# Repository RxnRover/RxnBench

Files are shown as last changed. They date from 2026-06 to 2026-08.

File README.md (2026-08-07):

# Rxn Bench - DIY Automated Chemistry Bench

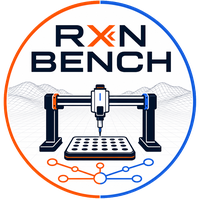
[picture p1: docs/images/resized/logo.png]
Rxn Bench logo


## Table of Contents

- [Overview](#overview)
- [Navigating this repository](#navigating-this-repository)
- [Requirements](#requirements)
- [Usage](#usage)
- [Implementation and design](#implementation-and-design)
- [Gallery](#gallery)
- [References and helpful material](#references-and-helpful-material)
- [Authors and Contributors](#authors-and-contributors)

## Overview

Rxn Bench is a DIY automated chemistry bench built on a repurposed Sovol SV08 3D printer as the XYZ motion platform, with an Atlas Scientific probe for pH sensing. A Raspberry Pi on the printer runs Klipper/Moonraker plus SiLA2 device servers for the gantry and pH sensor; a separate operator machine runs a frontend application [Rxn Bench](TODO: Eventually include repo link) that talks to those servers over gRPC/SiLA, and experiment scripts drive the bench through a Python client [Rxn Bench Client](TODO: Eventually include repo link).

### Motivation

Machine learning, high-throughput screening, and AI-assisted discovery all depend on large, reliable experimental datasets, and generating that data by hand is slow, inconsistent, and labor-intensive. Commercial automation platforms solve the repeatability problem, but most are costly, specialized, and locked to specific hardware and workflows - out of reach for many labs. Rxn Bench is a low-cost, modular alternative: off-the-shelf hardware, open lab-software frameworks, and customizable 3D-printed components, letting a lab integrate diverse devices, adapt workflows, and generate data at scale for under $1000.

## Navigating this repository

- [`rxnbench/`](rxnbench/) - app code that isn't specific to one device: `frontend/` (the desktop UI shell, discovery, device selection, generic fallback UI) and `backend/` (the uv workspace root, the shared `client/` Python API, install scripts).
- [`devices/`](devices/) - one self-contained plugin per physical device (`gantry`, `ph_sensor`, `camera`, `dosing_pump`), each split into a `capability/` (the SiLA2 server + operator-UI widget - hardware-agnostic) and a `driver/` (the actual vendor hardware code that plugs into it, plus that hardware's CAD and any mount/toolhead config). See [Supported-Devices.md](Supported-Devices.md) for which driver backs which capability. A device folder can be dropped in or removed without touching the app shell.
- [`hardware_models/`](hardware_models/) - placeholders for future devices without hardware yet. Each existing device's CAD lives with its driver instead - see `devices/<name>/driver/hardware_models/`.
- [`docs/`](docs/) - usage/deployment guides, architecture and design docs, datasheets, and the images used throughout this README.
- [`notes/`](notes/) - working notes.

See [docs/ai/CURRENT_STATE.md](docs/ai/CURRENT_STATE.md) for the full architecture snapshot, package layout, and active design decisions.

## Requirements

- A Sovol SV08 3D printer (or similar Klipper-based motion platform) and a computer device (__e.g. a Raspberry Pi 5__) to control it
- Python 3.10+ and [`uv`](https://docs.astral.sh/uv/) on both the Pi (backend) and the operator machine (frontend)
- Atlas Scientific EZO pH kit and 3D-printed mounts (see Component List below) for pH sensing hardware

## Usage

See [docs/usage.md](docs/usage.md) for commands to install dependencies and start the backend servers (real or mocked) and the frontend UI.

## Implementation and design

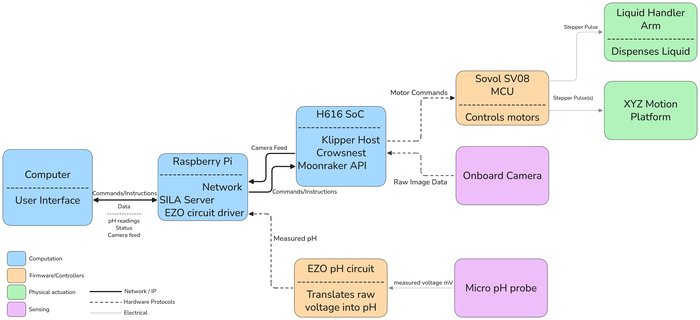
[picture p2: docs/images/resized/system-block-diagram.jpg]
Rxn Bench high-level system block diagram: operator UI talks to the Raspberry Pi's SILA server, which drives the Sovol SV08 MCU (XYZ motion), and the EZO pH circuit/probe


Rxn Bench is a modular lab-automation platform for programmable scientific workflows, built from a repurposed SOVOL SV08 3D printer with
custom 3D-printed components and open software interfaces.

### Capability-based hardware abstraction

Devices are represented through
SiLA2 feature servers running on a backend computer (e.g., a Raspberry Pi),
which expose standardized commands and properties for each capability:
pH sensor, gantry, pump, etc. New hardware plugs into the same feature
interface, so a device can be swapped or added with minimal frontend
and backend changes. If it walks like a duck and talks like a duck, it's
treated as a duck.

### Desktop control + Python API

[Rxn Bench](TODO: Eventually include repo link) provides a desktop
interface for configuration and direct device control, while a [Rxn Bench Client](TODO: Eventually include repo link) API
enables headless operation and experiment scripting.

### Component List

#### Motion Platform

| Name | Link | Purpose |
| --- | --- | --- |
| SV08 3D Printer | [MatterHackers](https://www.matterhackers.com/store/l/sovol-sv08-enclosed-pre-assembled-3d-printer/sk/MQ7MC2AK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) | XYZ motion platform base for liquid handler automation |
| Raspberry Pi 5  | [PiShop](https://www.pishop.us/product/raspberry-pi-5-8gb/?src=raspberrypi) | Main controller for coordinating motion and sensors |

#### pH Sensor

| Name | Link | Purpose |
| --- | --- | --- |
| Atlas Scientific EZO Micro pH Kit | [Atlas Scientific](https://atlas-scientific.com/kits/micro-ph-kit/) | Complete kit for pH measurement |
| Atlas Scientific EZO pH Circuit | [Atlas Scientific](https://atlas-scientific.com/embedded-solutions/ezo-ph-circuit/) | Embedded pH signal processing circuit |
| pH Isolation Board | [Atlas Scientific](https://atlas-scientific.com/carrier-boards/electrically-isolated-ezo-carrier-board-gen-2/) | Electrically isolates pH circuit to prevent noise/interference |
| Half-Cell pH Isolation Board | [Atlas Scientific](https://atlas-scientific.com/carrier-boards/half-cell/) | Carrier board for half-cell pH probe configurations |
| Spear Tip pH Probe | [Atlas Scientific](https://atlas-scientific.com/probes/spear-tip-ph-probe/) | Soil/spear-tip combination electrode; male SMA connector, mates directly to isolation carrier board |

#### Labware

##### Workspace

A workspace is a YAML-defined deck layout ([`devices/gantry/capability/backend/src/rxn_bench_gantry/workspace/`](devices/gantry/capability/backend/src/rxn_bench_gantry/workspace/)) that tells the gantry backend which labware sits where: sample plates, wash/waste beakers, a calibration station, and the washing station can all be mixed in whatever arrangement fits the deck and the experiment. Swapping workspaces (or editing one in the desktop UI's workspace editor) is a config change, not a rebuild - see [docs/usage.md](docs/usage.md) for how to load one.

##### Sample-Plates

3D-printed plate/tube holders that snap onto the deck's footprint grid. Each is a YAML labware definition under [`devices/gantry/capability/backend/src/rxn_bench_gantry/labware/`](devices/gantry/capability/backend/src/rxn_bench_gantry/labware/), the single source of truth for well geometry, plate height, and the gantry's clearance/engagement-depth math.

| Name | Wells | Purpose |
| --- | ----- | --- |
| 96-Well Standard Plate | 8x12  | High-density standard well plate  |
| 24-Well Standard Plate | 4x6 | Square-well standard plate |
| 24-Well Sample Holder (5 mL) | 4x6 | Holds 5 mL vials |
| 24-Well Sample Holder (15 mL)  | 4x6 | Holds 15 mL vials |
| 15-Well Sample Holder | 3x5 | Holds large-format samples |
| 6-Well Sample Holder (25 mL) | 2x3 | Holds 25 mL vials |
| 6-Well Sample Holder (50 mL) | 2x3 | Holds 50 mL vials |
| 3-Well Sample Holder | 1x3 | Holds large-diameter samples |
| 100 mL Beaker Holder | 1x1 | Wash/waste reservoir |

##### Footprints

Every piece of labware shares the same footprint (127.76 x 85.48 mm - the ANSI/SBS standard microplate footprint), so any plate, tube holder, beaker, or the washing station locks into the same modular grid of mounting tiles on the deck. Swapping a 6-well tube rack for a 96-well plate is a matter of physically swapping footprints and pointing the workspace YAML at the new labware, not redesigning the deck.

##### Washing-Station

A 3D-printed cup, routed to waste through tubing, used to rinse the pH probe (or future pipette tips) between wells. It is defined as its own labware footprint ([`washing_station.yaml`](devices/gantry/capability/backend/src/rxn_bench_gantry/labware/washing_station.yaml)) so it slots into a workspace exactly like any other plate.

###### Liquid Handler (In-progress)

| Name | Link | Purpose |
| --- | --- | --- |
| Pipette Cone Assembly | [PipetteSupplies](https://www.pipettesupplies.com/product/e1-clip-tip-tip-cone-assembly-single-channel-1250-l-t/) | Actual liquid displacement mechanism |
| Stepper Linear Actuator | [Haydon Kerk Pittman](https://www.haydonkerkpittman.com/products/linear-actuators/can-stack-stepper) | Pushes the pipette plunger to aspirate/dispense liquid |

#### Extra Peripherals

| Name | Link | Purpose |
| --- | --- | --- |
| SMA Male-to-Female Extender Cable | [Atlas Scientific](https://atlas-scientific.com/accessories/sma-extender/) | Extends the probe cable reach from the carrier board to the mounted probe |

#### Other components/items

| Name | Link | Purpose |
| --- | --- | --- |
| Bambu Lab A1 | [BambuLabs](https://bambulab.com/en-us/a1) | Unmodified used to 3D print platforms, plates, etc. |

## Gallery

### Assembled bench

| Assembled, pipette over a well plate | Running on the bench next to the operator laptop |
| --- | --- |
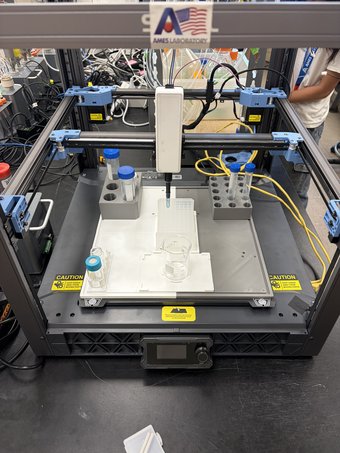
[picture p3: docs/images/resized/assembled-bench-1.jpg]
Assembled Rxn Bench with the pipette toolhead positioned over a well plate
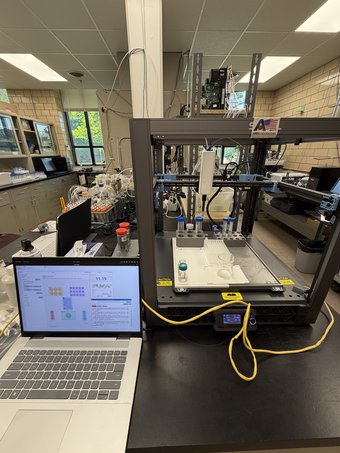
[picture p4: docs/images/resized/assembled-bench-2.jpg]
Rxn Bench running on the lab bench next to the operator laptop running the frontend UI
|  |  |

### pH probe toolhead

CAD design next to the assembled 3D-printed housing around the Atlas Scientific EZO pH circuit and probe.

| CAD design | Assembled |
| --- | --- |
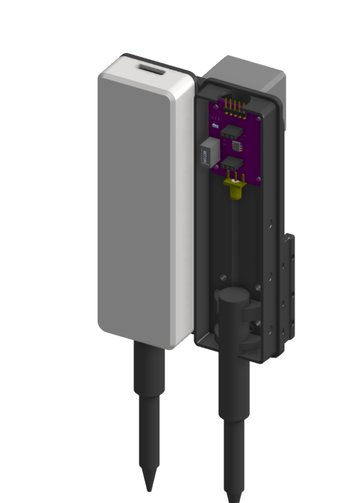
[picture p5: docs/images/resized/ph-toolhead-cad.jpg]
CAD render of the pH probe toolhead, exploded to show the EZO pH circuit board inside
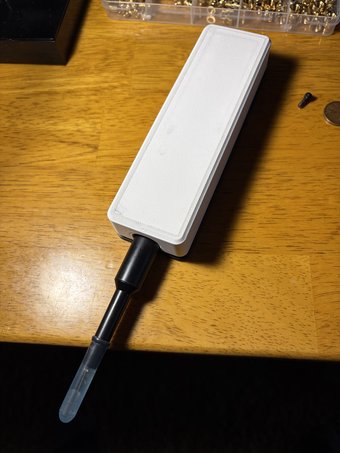
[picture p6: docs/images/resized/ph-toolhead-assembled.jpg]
Assembled 3D-printed pH probe toolhead housing
|  |  |

### Toolhead docking mount

The gantry docks multiple toolheads via a 3D-printed mount with linear-rails, in the spirit of the tool-changer designs linked below.

| CAD design | Assembled |
| --- | --- |
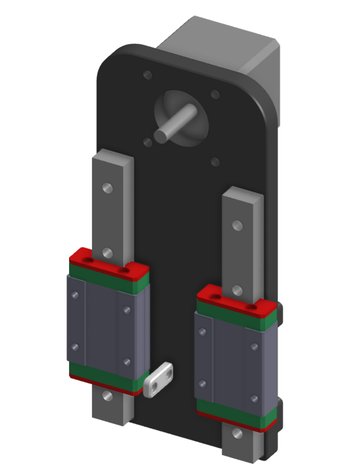
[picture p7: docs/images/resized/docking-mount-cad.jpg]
CAD render of the toolhead docking mount with linear rail bearings
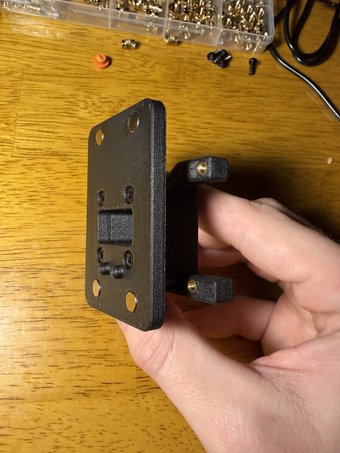
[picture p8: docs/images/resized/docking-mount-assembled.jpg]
Assembled 3D-printed toolhead docking mount
|  |  |

### Labware

#### Workspace

| Planned layout | Assembled deck |
| --- | --- |
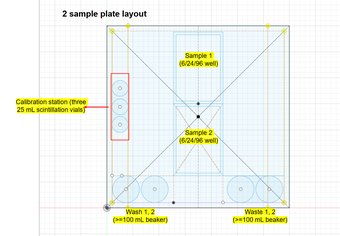
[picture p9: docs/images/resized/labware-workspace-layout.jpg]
Example workspace layout diagram showing sample plates, wash/waste beakers, a calibration station, and a pipette-tip disposal zone arranged on the deck
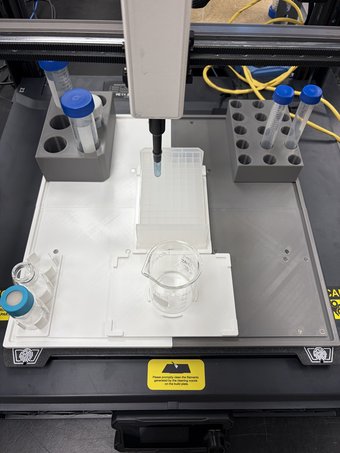
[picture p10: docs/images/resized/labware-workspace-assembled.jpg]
Assembled deck with sample holders, a 96-well plate, and a beaker mounted on the footprint grid
|  |  |

#### Sample-Plates

| 24-Well Sample Holder | 15-Well Sample Holder |
| --- | --- |
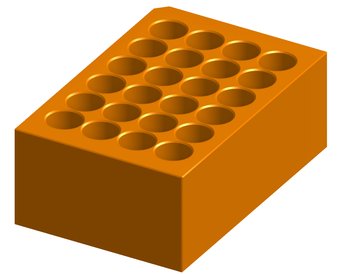
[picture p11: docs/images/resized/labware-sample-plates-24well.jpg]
CAD render of the 24-well sample holder block
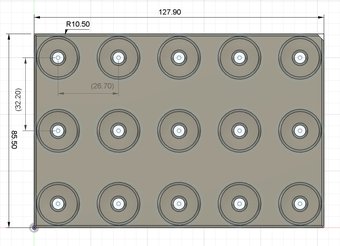
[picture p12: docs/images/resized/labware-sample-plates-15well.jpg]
Dimensioned CAD drawing of the 15-well sample holder
|  |  |

#### Footprints

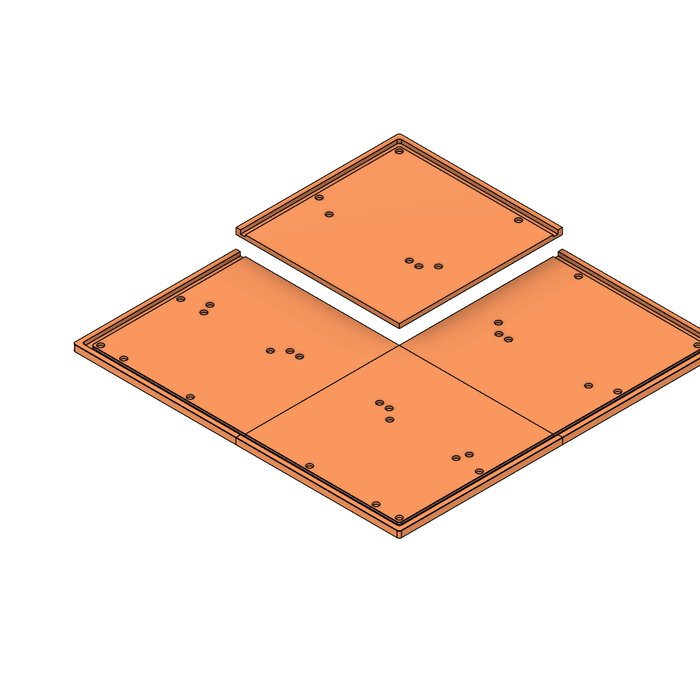
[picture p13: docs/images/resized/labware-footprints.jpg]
CAD render of the modular footprint tiles that labware mounts onto, shown apart from the deck


#### Washing-Station

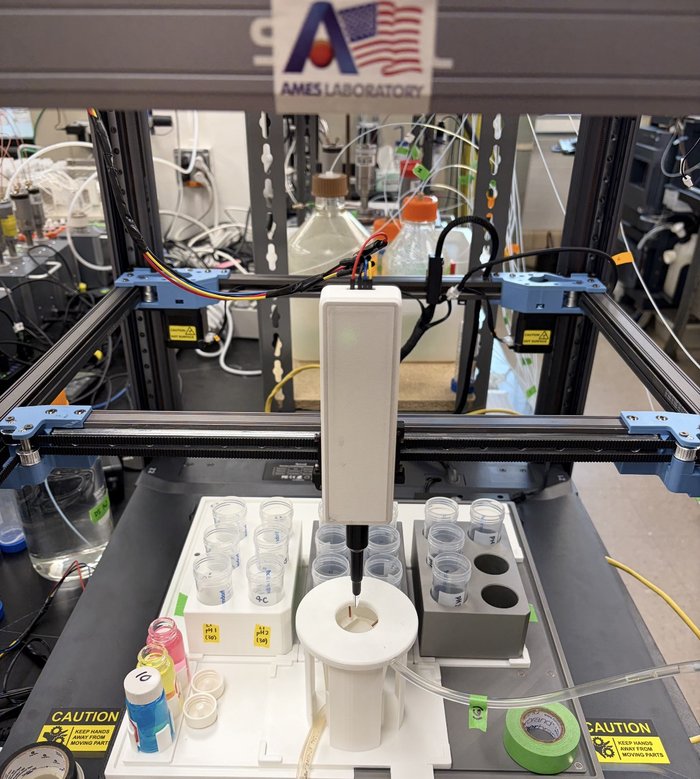
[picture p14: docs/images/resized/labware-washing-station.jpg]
The pH probe toolhead docked over the washing station cup, flanked by sample holders on the deck


### Rxn Bench UI

#### Main interface

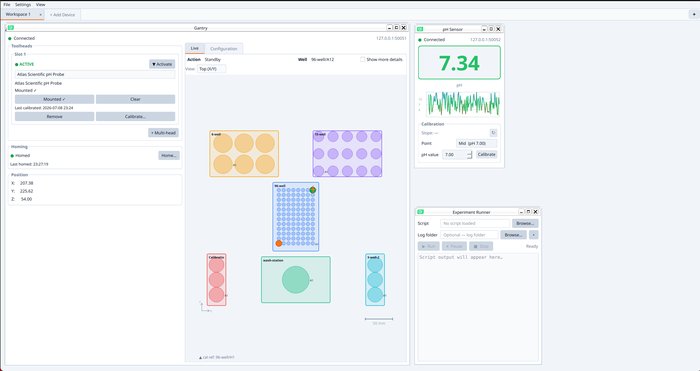
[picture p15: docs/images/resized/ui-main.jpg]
Rxn Bench UI main screen showing the Gantry widget, pH Sensor widget, and Experiment Runner widget


#### Sensor and control widgets

| Gantry | pH Probe | Experiment Runner |
| --- | --- | --- |
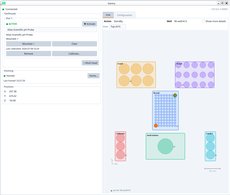
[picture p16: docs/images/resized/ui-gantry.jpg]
Gantry view
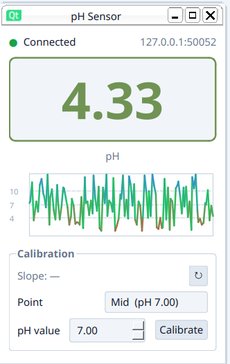
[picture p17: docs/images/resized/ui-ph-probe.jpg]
pH Probe view
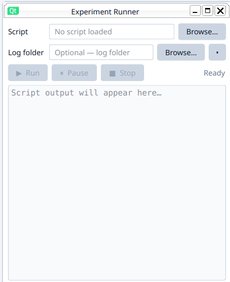
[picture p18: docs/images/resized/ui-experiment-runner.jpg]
Experiment Runner view
|  |  |  |

#### Adding a device

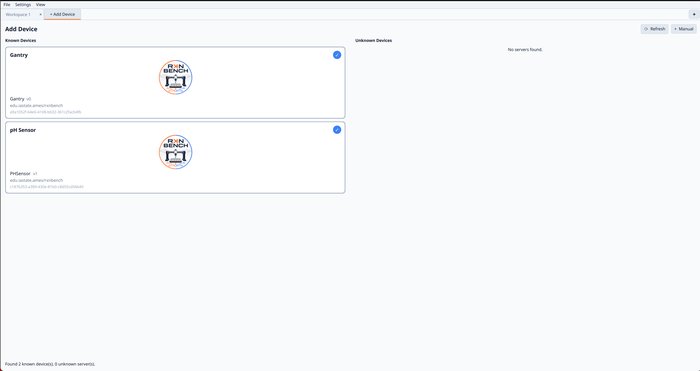
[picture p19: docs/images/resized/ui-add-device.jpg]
Add Device view


## References and helpful material

### Core

- [How to convert a 3D printer to a personal automated liquid handler for life science workflows](https://www.sciencedirect.com/science/article/pii/S2472630324001213#bib0043)
- [Opentrons](https://opentrons.com/) - commercial lab-automation platform, referenced for cost/rigidity comparison
- [SILA Standard](https://sila-standard.com/standards/)
- [SILA Standard GitLab](https://gitlab.com/SiLA2)
- [Klipper Firmware](https://www.klipper3d.org/)
- [SOVOL SV08 GitHub](https://github.com/Sovol3d/SV08)
- [Raspberry Pi Docs](https://www.raspberrypi.com/documentation/computers/raspberry-pi.html)
- [Crowsnest](https://docs.mainsail.xyz/crowsnest/)
- [Moonraker](https://moonraker.readthedocs.io/en/latest/)
- [Pipette Clip Tip](https://www.thermofisher.com/us/en/home/life-science/lab-plasticware-supplies/pipettes-pipette-tips/pipette-tips/products/cliptip-pipette-system.html)

### Related open-source lab automation projects

- [Rxn Rover](https://rxnrover.github.io/) - Ames National Lab Automation Platform
- [Science Jubilee](https://science-jubilee.readthedocs.io/) - open-source tool-changing lab robot with pipette, camera, and sensor tools
- [Jubilee: An Extensible Machine for Multi-tool Fabrication (paper)](https://www.researchgate.net/publication/341697828_Jubilee_An_Extensible_Machine_for_Multi-tool_Fabrication)
- [Automated Liquid Handler from a 3D Printer - Journal of Chemical Education](https://pubs.acs.org/doi/10.1021/acs.jchemed.3c00855)
- [E3D Tool Changer R&D](https://e3d-online.com/blogs/news/research-and-development-motion-system-and-tool-changer) - commercial tool-changer that inspired Jubilee's docking mechanism
- [GitHub - totaldesaster/toolchanger](https://github.com/totaldesaster/toolchanger) - low-cost 3D-printed tool changer mechanism
- [EvoBot: Open-Source Modular Liquid Handling Robot](https://www.mdpi.com/2076-3417/10/3/814)
- [Open-source personal pipetting robots (Nature Communications)](https://www.nature.com/articles/s41467-022-30643-7)

## Authors and Contributors

### Co-authors

__John Brittain__* - Software development, system design, hardware design, fabrication, integration, and project lead for the Rxn Bench platform.

__Felisha Kuo__* - Experimental setup, laboratory workflow development, hardware fabrication, testing, and project lead for the chemistry-side integration.

__David Lee__ - Laboratory expertise, practical setup support, equipment ordering, and experimental workflow insight.

__Lun An__ - Chemistry supervision, project planning, experimental guidance, chemistry expertise, and technical review.

__Long Qi__ - Project sponsorship, overall direction, supervision, planning, and organizational guidance.

__Zachery Crandall__ - Engineering and software supervision, project planning, technical guidance, and formal review.

*These authors contributed equally to the work.

### Acknowledgements

This work was supported by the [SuLI internship program](https://science.osti.gov/wdts/suli) at [Ames National Laboratory](https://www.ameslab.gov/). The authors thank the program organizers and mentors for providing the opportunity, resources, and guidance that made this project possible.

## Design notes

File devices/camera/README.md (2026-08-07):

# Camera

Streams periodic still images over SiLA. `CameraProtocol` only requires a `capture() -> bytes` method, so the capability doesn't care what's behind it.

- **`capability/`** - the SiLA feature + PySide6 widget. `capability/backend/` is `rxn-bench-camera` (port 50053, runs on the device host alongside `rxn-bench-gantry`/`rxn-bench-ph` - a Raspberry Pi in the reference deployment). `capability/frontend/` is the Camera device plugin (live image view, capture-interval control). See [capability/backend/README.md](capability/backend/README.md) for the full SiLA feature list.
- **`driver/`** - `rxn-bench-crowsnest-camera-driver`, which pulls stills from a Crowsnest-managed webcam over HTTP (initial target: the Crowsnest stream on the SOVOL SV08's own controller). Swap this for a different camera source's driver without touching the SiLA feature or widget. See [Supported-Devices.md](../../Supported-Devices.md).

`capability/backend/` and `driver/backend/` both only ever run on the device host; `capability/frontend/` only ever runs on the operator machine as part of `rxn_bench_ui` (SiLA/gRPC only, no direct imports). See [docs/ai/CURRENT_STATE.md](../../docs/ai/CURRENT_STATE.md) for the full architecture.

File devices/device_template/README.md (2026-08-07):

# device_template

Boilerplate for adding a new device to the rxn bench, not a real device itself. Copy this whole folder to `devices/<name>/` and follow the checklist.

- **`capability/`** - reference SiLA feature + widget. `capability/backend/` is the reference SiLA2 server package (`rxn_bench_template`), with `TODO`-marked stubs for the hardware `Protocol`, SiLA feature, mock, and server wiring. Start here: [capability/backend/README.md](capability/backend/README.md) has the full step-by-step checklist for renaming and wiring things up. `capability/frontend/` is the reference device plugin: a minimal hand-built widget (no `.ui` file) plus the standard connection layer. Wire decoding uses compiled protobuf stubs in `capability/frontend/src/rxn_bench_device_template_frontend/proto/`, generated from the device's manifest entry in `rxnbench/backend/scripts/gen_proto.py` (run `make gen-proto` from `rxnbench/backend`). Delete the frontend half if your device doesn't need a custom widget yet - unrecognized servers fall back to the generic `GenericDeviceWidget`.

There's no `driver/` here on purpose - this template's mock is a generic Protocol stub, not real vendor hardware, so there's nothing to split out yet. A real device usually does need one: see `devices/ph_sensor/` for the fullest worked example (a driver with two transports, hardware CAD, and a toolhead config) and [Supported-Devices.md](../../Supported-Devices.md) for how capability/driver packages register with each other.

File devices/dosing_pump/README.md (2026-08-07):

# dosing_pump

Dosing pump SiLA feature, exposed as `DosingPump` on port **50054**. Hardware-agnostic - the reference hardware is the Atlas Scientific **EZO-PMP**, but that's a driver, not baked into the feature.

- **`capability/`** - the SiLA feature + PySide6 widget. `capability/backend/` is `rxn-bench-dosing-pump`. `capability/frontend/` is the widget: dispense / dose-over-time / flow-rate controls, live dispensed volume, totals. See [capability/backend/README.md](capability/backend/README.md) for the command set.
- **`driver/`** - `rxn-bench-atlas-ezo-pmp-driver`, the Atlas Scientific EZO-PMP UART driver (including its mock - see "Reusing this for a different pump" below for why the mock lives here too). Swap this for a different pump's driver without touching the SiLA feature or widget. See [Supported-Devices.md](../../Supported-Devices.md).

## Hardware at a glance

| | |
|---|---|
| Flow rate | 0.5 - 105 ml/min open-loop (with the supplied tubing) |
| Metered rate ceiling | Lower than 105, reported by `DC,?`, set by calibration |
| Smallest dispense | 0.5 ml |
| Accuracy | ±1% (after calibration) |
| Data protocol | UART (implemented) or I2C, ASCII |
| UART default | 9600 baud, 8N1, CR-terminated |
| Power | 3.3-5.5 V logic **and** 12-24 V motor (two supplies) |

Datasheet: [docs/datasheets-manuals/EZO-PMP/EZO_PMP_Datasheet.pdf](../../docs/datasheets-manuals/EZO-PMP/EZO_PMP_Datasheet.pdf)

## Operating modes

All four datasheet modes are exposed:

| Mode | SiLA command | EZO command |
|---|---|---|
| Volume dispensing | `Dispense(Volume)` | `D,[ml]` |
| Dose over time | `DoseOverTime(Volume, Minutes)` | `D,[ml],[min]` |
| Constant flow rate | `SetFlowRate(Rate, Minutes)` | `DC,[ml/min],[min\|*]` |
| Continuous dispensing | `DispenseContinuously(Reverse)` | `D,*` / `D,-*` |

Dispense-at-startup (`Dstart`) is deliberately not exposed - it configures the pump to run on power-up without a client, which works against having the bench drive it.

### Two different maxima

These are easy to conflate:

- **~105 ml/min** - the pump's *open-loop* top speed with the supplied tubing, and the datasheet cover's "0.5ml to 105ml/min". This is what **Continuous** (`D,*`) runs at. It takes no rate argument; the motor just runs flat out.
- **`MaxFlowRate` (`DC,?`)** - the fastest rate the pump can *regulate* to in **Constant rate** mode. Substantially lower (the datasheet's example is 58.5 ml/min) and "determined after calibration". Asking `SetFlowRate` for more returns `*TOOFAST`.

So a rate you can *hold* is always below the rate the pump can *reach*. To run continuously **at a chosen rate**, use Constant rate with an open-ended duration (`DC,[rate],*`) - not Continuous:

```python
bench.pump.set_flow_rate(2.0)        # 2 ml/min until stopped
bench.pump.dispense_continuously()   # ~105 ml/min until stopped, rate not settable
```

## Quick start

```bash
# from rxnbench/backend
RXN_BENCH_MOCK=1 uv run --package rxn-bench-dosing-pump rxn-bench-dosing-pump
make test-pump
```

From an experiment script:

```python
from rxn_bench_client import RxnBenchClient, DosingPump

with RxnBenchClient() as bench:
    bench.connect("pump", DosingPump, server="Dosing Pump")
    bench.pump.dispense_and_wait(5.0)      # blocks until delivered
    bench.log(dispensed=bench.pump.total_volume())
```

## Reusing this for a different pump

Everything in `capability/` is model-agnostic, because the frontend is matched to the **SiLA feature**, not the hardware: `rxn_bench_ui` discovers plugins by comparing advertised feature identifiers against `FEATURE_FRAGMENTS`. Any server advertising `DosingPump` gets this widget.

So a second pump model needs **its own driver package** - no changes to the capability (feature, proto, connection layer, client, or widget):

1. Write a driver satisfying [`DosingPumpProtocol`](capability/backend/src/rxn_bench_dosing_pump/interfaces.py) (12 methods) in a new package, e.g. `rxn_bench_<vendor>_driver`.
2. Register it in that package's `pyproject.toml` under the `rxn_bench.dosing_pump_drivers` entry-point group, pointing at a factory function (see [`driver/backend/pyproject.toml`](driver/backend/pyproject.toml) for the exact shape). Select it at runtime with `RXN_BENCH_PUMP_DRIVER=<your-entry-point-name>` (default: `atlas_ezo_pmp`).

`capability/backend/src/rxn_bench_dosing_pump/server.py` never imports a concrete driver - it just asks the entry-point registry for whichever name `RXN_BENCH_PUMP_DRIVER` names. If the new pump also happens to be a distinct physical device you want running *alongside* the EZO-PMP, give it its own `devices/<name>/` with its own capability, port, and config - but still register the same `DosingPump` feature, and it reuses the same widget automatically.

### What the core interface deliberately excludes

`DosingPumpProtocol` covers only what any dosing pump can do (dispense by volume / over time / at a rate / continuously, pause, stop, totals, state). Three things are **opt-in capability protocols**, because they aren't universal:

| Capability protocol | Methods | Why it's optional |
| --- | --- | --- |
| `SupportsCalibration` | `calibrate`, `clear_calibration`, `calibration_status` | Many pumps are calibrated externally or not at all |
| `SupportsDirectionInvert` | `set_inverted`, `is_inverted` | A *persistent* direction flip is an EZO feature; most pumps just take a signed volume |
| `SupportsDiagnostics` | `pump_voltage` | Motor supply sensing; a syringe pump has no equivalent |

They're `runtime_checkable`, so the feature tests them with `isinstance` and rejects just those commands - with a message naming what's missing - on a pump that lacks them. The SiLA surface stays identical for every model, so one proto and one widget serve all of them.

## Two things to check before running real hardware

1. **Serial port.** The reference bench already runs the EZO-pH on the Pi's primary UART (`/dev/serial0` -> `/dev/ttyAMA0`). The pump needs its own port - a second PL011 (`dtoverlay=uartN` in `/boot/firmware/config.txt`) or a USB-serial adapter - set via `RXN_BENCH_PUMP_SERIAL_PORT`. On the reference Pi 5, `dtoverlay=uart2` puts UART2 on GPIO4/5 as `/dev/ttyAMA2`; confirmed against the real EZO-PMP 2026-08-04 (`?I`, `?STATUS`, and `PV,?` all responded correctly, motor supply read 11.99 V). `install_service.sh` sets this port automatically for the `pump` service.
2. **Calibration.** An uncalibrated pump's volumes are nominal. Dispense into a graduated container, then send the measured volume with `Calibrate`. `MaxFlowRate` is only meaningful after calibration.

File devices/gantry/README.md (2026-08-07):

# Gantry

The XYZ motion device: manages toolhead geometry, workspace/well-plate layout, and homing state. Hardware-agnostic - the actual motion controller is a driver, not baked in.

- **`capability/`** - the SiLA feature + PySide6 widget. `capability/backend/` is `rxn-bench-gantry` (port 50051, runs on the device host - a Raspberry Pi in the reference deployment). `capability/frontend/` is the gantry device plugin. See [capability/backend/README.md](capability/backend/README.md) for the full SiLA feature list, configuration, and how to add a toolhead or well plate.
- **`driver/`** - `rxn-bench-moonraker-driver`, the Moonraker/Klipper motion controller code (reference hardware: Sovol SV08 3D printer), plus its mounting-hardware CAD in `driver/hardware_models/`. This is what makes the gantry move; swap it for a different motion controller's driver without touching the SiLA feature or widget. See [Supported-Devices.md](../../Supported-Devices.md).

`capability/backend/` and `driver/backend/` both only ever run on the device host; `capability/frontend/` only ever runs on the operator machine as part of `rxn_bench_ui` (SiLA/gRPC only, no direct imports). See [docs/ai/CURRENT_STATE.md](../../docs/ai/CURRENT_STATE.md) for the full architecture.

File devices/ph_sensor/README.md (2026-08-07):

# pH Sensor

Streams pH readings with mid/low/high three-point calibration. Hardware-agnostic - the actual probe driver is separate, not baked in.

- **`capability/`** - the SiLA feature + PySide6 widget. `capability/backend/` is `rxn-bench-ph` (port 50052, runs on the device host alongside `rxn-bench-gantry` - a Raspberry Pi in the reference deployment). `capability/frontend/` is the pH device plugin (live reading graph, calibration controls). See [capability/backend/README.md](capability/backend/README.md) for the full SiLA feature list and calibration workflow.
- **`driver/`** - `rxn-bench-atlas-ezo-ph-driver`, the Atlas Scientific EZO-pH circuit driver (I2C or UART), plus the probe's toolhead mount CAD in `driver/hardware_models/` and its gantry toolhead config in `driver/toolhead/`. Swap this for a different pH probe's driver without touching the SiLA feature or widget. See [Supported-Devices.md](../../Supported-Devices.md).

`capability/backend/` and `driver/backend/` both only ever run on the device host; `capability/frontend/` only ever runs on the operator machine as part of `rxn_bench_ui` (SiLA/gRPC only, no direct imports). See [docs/ai/CURRENT_STATE.md](../../docs/ai/CURRENT_STATE.md) for the full architecture.

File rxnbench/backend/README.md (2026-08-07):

# Rxn Bench Server

The device side of the Rxn Bench. Each device is an independent SiLA2 server:

| Server | Command | Port  |
| --- | --- | ----- |
| Gantry | `rxn-bench-gantry` | 50051 |
| pH sensor | `rxn-bench-ph` | 50052 |
| Camera | `rxn-bench-camera` | 50053 |
| <device> | `rxn-bench-<device>| 5005x |

Also hosts [`client/`](client/README.md) - the `rxn-bench-client` Python package
experiment scripts use to drive the bench. Run all commands below from this directory

## Requirements

- Python 3.10+ and [`uv`](https://docs.astral.sh/uv/)

## Install

```bash
uv sync
```

On the device host (a Raspberry Pi in the reference deployment), `./install.sh`
wraps this, installs `uv` if missing, and adds the pH sensor's I2C deps on ARM.

## Start the servers

### Mock hardware (no physical bench needed)

```bash
make start-mock                       # all three, in the background
# or one at a time:
RXN_BENCH_MOCK=1 uv run rxn-bench-gantry
```

Stop the background mocks with `pkill -f rxn-bench-gantry` (and `-ph`, `-camera`).

### Real hardware

```bash
make start-gantry     # or: uv run rxn-bench-gantry
make start-ph         # or: uv run rxn-bench-ph
make start-camera     # or: uv run rxn-bench-camera
```

Each server reads `~/.rxn_bench/<name>.json` if present, else the bundled
`<package>/configs/<name>.json`. Override with `--config /path/to/file.json`.

## Test

```bash
make test             # all devices + client (or: make test-gantry / test-ph / test-camera / test-client)
```

## Regenerate proto stubs

After changing a device's SiLA feature/command manifest:

```bash
make gen-proto        # writes devices/<name>/capability/frontend/src/*/proto/*.proto (+ _pb2.py)
make check-proto      # CI drift check
```

## Production / offline deployment

Install each server as its own systemd service, or build an offline bundle for a
Pi with no internet. See [../../docs/usage.md](../../docs/usage.md) and
[../../docs/deployment.md](../../docs/deployment.md).

## Updating the Pi over SSH

Quick note for pushing a code change to the reference bench Pi. The Pi lives on
the isolated, gatewayless bench network, so it has **no internet** - you can't
`git pull` on it. Get the new source over from your dev machine, then restart.

```bash
# 1. From your dev machine (plugged into the bench switch): sync the repo over.
#    scp/USB works too; rsync just skips unchanged files.
rsync -av --delete \
  --exclude '.venv' --exclude '__pycache__' --exclude '.git' \
  ./ <user>@192.168.50.1:~/Automated_Chem_Bench/

# 2. SSH in and restart the service(s) you changed.
ssh <user>@192.168.50.1
sudo systemctl restart rxn-bench-gantry   # or rxn-bench-ph / rxn-bench-camera

# 3. Confirm it came back up.
sudo systemctl status rxn-bench-gantry
journalctl -u rxn-bench-gantry -f
```

The services are **editable** installs (`uv pip install -e`), so a plain
`systemctl restart` picks up Python source changes - no venv rebuild needed.

Rebuild the venv only when it's more than source, by re-running the installer
for that one device (rebuilds its `.venv`, restarts only its service):

```bash
cd ~/Automated_Chem_Bench/rxnbench/backend
./scripts/install_service.sh gantry
```

Do that when: dependencies changed (`pyproject.toml`), a driver setup step
changed, or you added a new device. Changes to `~/.rxn_bench/<device>.json`
(e.g. the advertise IP) just need a `systemctl restart`.

Service <-> device names: `rxn-bench-gantry`, `rxn-bench-ph`, `rxn-bench-camera`.
The Pi's bench address `192.168.50.1` is static and never changes. See
[../../docs/deployment.md](../../docs/deployment.md) for the full ops story.

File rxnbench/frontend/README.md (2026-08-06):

# Rxn Bench (UI)

Desktop control app for the Rxn Bench. It discovers the backend SiLA2 device
servers (gantry, pH, camera) over mDNS on the local network and drives them over
gRPC. Device widgets are plugins - the 5 shipped devices are installed packages
under `devices/*/capability/frontend/`, discovered via a Python entry point;
a flat `devices/<name>/frontend/` (no install needed) still works too, as a
drop-in fallback for a new/experimental device. See `docs/ai/CURRENT_STATE.md` §2.

Runs on a separate machine from the backend - all data goes over SiLA/gRPC.

## Requirements

- Python 3.10+ and [`uv`](https://docs.astral.sh/uv/)
- For building a distribution: the `package` dependency group (PyInstaller), pulled in with `uv sync --group package`

## Run in development

```bash
uv sync
uv run rxn-bench-ui
```

The UI finds any running servers automatically (mock or real - see
[../backend/README.md](../backend/README.md) to start them).

## Build a distribution

PyInstaller can't cross-compile, so build on the OS you're targeting.

### Linux

```bash
make dist          # onedir build -> dist/Rxn Bench/
make dist-check    # optional: constructs every device widget in the frozen build to catch missing deps
"./dist/Rxn Bench/Rxn Bench"
```

`make dist` bakes the 5 shipped devices into the build directly (they're real
dependencies of `rxn-bench-ui`, not staged folders) - adding one of those
needs a rebuild. It also stages any flat `devices/<name>/frontend/` (the
fallback path above) next to the executable, so *that* kind of device still
works as a true no-rebuild drop-in.

### Windows installer

```bash
make installer     # -> dist-installer/Rxn-Bench-Setup-<version>.exe
```

Requires [Inno Setup](https://jrsoftware.org/isinfo.php)'s `ISCC.exe` on `PATH`
(Windows only). The installer is per-user by default (no admin needed) and
version is read from `pyproject.toml`.

Easiest way to produce the Windows `.exe` from a Linux dev machine: push a `v*`
tag (or run the **Windows installer** workflow manually). GitHub Actions
(`.github/workflows/windows-installer.yml`) builds it on a `windows-latest`
runner and attaches the installer to the tagged GitHub Release.

## Test

```bash
make test          # headless generator/error/geometry tests
```

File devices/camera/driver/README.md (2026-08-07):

# rxn-bench-crowsnest-camera-driver

Pulls still images from a Crowsnest-managed webcam stream over plain HTTP. Reference deployment: the Crowsnest instance running on the Sovol SV08's own controller.

- `backend/` - `rxn_bench_crowsnest_camera_driver`, registered under the `rxn_bench.camera_drivers` entry-point group as `crowsnest`. Implements `CameraProtocol` (one method: `capture() -> bytes`) - no dependency on the capability package at all, since Crowsnest's HTTP snapshot endpoint needs nothing from it.

This package is never imported directly by the capability - `rxn_bench_camera.server` discovers it (or any other registered camera driver) via `importlib.metadata.entry_points(group="rxn_bench.camera_drivers")`, selectable with `RXN_BENCH_CAMERA_DRIVER` (default: `crowsnest`). See `../capability/backend/README.md` for how to run the server and configure `crowsnest_base_url`/`crowsnest_snapshot_path`, and `docs/ai/CURRENT_STATE.md` §1 for the full capability/driver design.

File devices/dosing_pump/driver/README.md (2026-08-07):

# rxn-bench-atlas-ezo-pmp-driver

The Atlas Scientific EZO-PMP peristaltic pump driver, over UART.

- `backend/` - `rxn_bench_atlas_ezo_pmp_driver`, registered under the `rxn_bench.dosing_pump_drivers` entry-point group with **two** entries: `atlas_ezo_pmp` (real hardware) and `atlas_ezo_pmp_mock` (the `RXN_BENCH_MOCK=1` path). Implements `DosingPumpProtocol` from the capability package (`../capability/backend/`) - that's the only thing it depends on there.

The mock lives here rather than in the capability on purpose: `MockDosingPump` subclasses `AtlasDosingPump` and runs the real driver stack over a protocol emulator (`MockEZOPumpUart`) instead of stubbing the Protocol directly, so it exercises the same command encoding/timing the bench uses. That makes it genuinely driver-specific - see `backend/src/rxn_bench_atlas_ezo_pmp_driver/mock_device.py`.

This package is never imported directly by the capability - `rxn_bench_dosing_pump.server` discovers it (or any other registered pump driver) via `importlib.metadata.entry_points(group="rxn_bench.dosing_pump_drivers")`, selectable with `RXN_BENCH_PUMP_DRIVER` (default: `atlas_ezo_pmp`). See `../capability/backend/README.md` for the command set, wiring, and protocol notes, and `docs/ai/CURRENT_STATE.md` §1 for the full capability/driver design.

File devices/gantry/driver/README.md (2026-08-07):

# rxn-bench-moonraker-driver

The gantry's motion driver: talks to Moonraker (Klipper's REST API) to actually move the XYZ carriage. Reference hardware: a Sovol SV08 3D printer.

- `backend/` - `rxn_bench_moonraker_driver`, registered under the `rxn_bench.gantry_drivers` entry-point group as `moonraker`. Implements `MotionClientProtocol` from the capability package (`../capability/backend/`) - that's the only thing it depends on there.
- `hardware_models/` - SV08 mounting brackets, belt clamps, and other platform-specific 3D-printable parts.

This package is never imported directly by the capability - `rxn_bench_gantry.server` discovers it (or any other registered gantry driver) via `importlib.metadata.entry_points(group="rxn_bench.gantry_drivers")`, selectable with `RXN_BENCH_GANTRY_DRIVER` (default: `moonraker`). See `../capability/backend/README.md` for how to run the server, and `docs/ai/CURRENT_STATE.md` §1 for the full capability/driver design.

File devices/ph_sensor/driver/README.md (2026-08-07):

# rxn-bench-atlas-ezo-ph-driver

The Atlas Scientific EZO-pH circuit driver, over either I2C or UART.

- `backend/` - `rxn_bench_atlas_ezo_ph_driver`, registered under the `rxn_bench.ph_drivers` entry-point group as `atlas_ezo`. Implements `PHSensorProtocol` from the capability package (`../capability/backend/`) - that's the only thing it depends on there. Transport is chosen at runtime with `RXN_BENCH_PH_TRANSPORT` (`i2c` default, or `uart`); see `build_sensor()` in `backend/src/rxn_bench_atlas_ezo_ph_driver/__init__.py` for the exact env vars.
- `hardware_models/` - the pH probe's toolhead mount CAD.
- `toolhead/ph_probe_toolhead.yaml` - the probe's gantry mount geometry (footprint, tip offsets, engage depth). This is data the gantry needs but doesn't own - `rxnbench/backend/scripts/aggregate_toolheads.py` copies it into the gantry capability's bundled `toolheads/` directory at install time. Edit it here, not the copy that shows up there.

This package is never imported directly by the capability - `rxn_bench_ph.server` discovers it (or any other registered pH driver) via `importlib.metadata.entry_points(group="rxn_bench.ph_drivers")`, selectable with `RXN_BENCH_PH_DRIVER` (default: `atlas_ezo`). See `../capability/backend/README.md` for how to run the server, and `docs/ai/CURRENT_STATE.md` §1 for the full capability/driver design.

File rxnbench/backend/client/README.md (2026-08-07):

# rxn-bench-client

Blocking Python client for writing experiment scripts that run on the backend machine. Wraps `sila2.SilaClient` connections to instrument servers (gantry on port 50051, pH sensor on port 50052) and exposes common operations as simple method calls through per-instrument strategy classes.

This is a library, not a server - it has no entry point and no SiLA server of its own.

---

## Requirements

- Python 3.10+
- [`uv`](https://docs.astral.sh/uv/) - install with `curl -LsSf https://astral.sh/uv/install.sh | sh`
- `rxn-bench-gantry` and/or `rxn-bench-ph` running (locally, mocked, or on a remote device host) - see [../../../docs/usage.md](../../../docs/usage.md)

Install from the workspace root:

```bash
cd rxnbench/backend
uv sync
```

---

## Usage

### Basic experiment script

```python
from rxn_bench_client import RxnBenchClient, Gantry, PHProbe

with RxnBenchClient() as bench:
    # Server names are discovered automatically on the local network (mDNS).
    bench.connect("gantry", Gantry, server="Gantry")
    bench.connect("ph", PHProbe, server="pH")

    bench.set_log_output("results/scan.csv")
    bench.gantry.load_workspace_yaml()
    bench.gantry.mount_toolhead("ph_probe")

    for well in bench.gantry.get_workspace_wells("plate1"):
        with bench.at_well(well, stabilize=3):
            bench.log(ph=bench.ph.read())  # well is saved to the log automatically

    bench.gantry.save_and_park()
```

### Connecting explicitly (e.g. a remote device host)

Skip mDNS discovery by passing `host`/`port` instead of `server`:

```python
with RxnBenchClient() as bench:
    bench.connect("gantry", Gantry, host="192.168.1.42", port=50051)
    bench.connect("ph", PHProbe, host="192.168.1.42", port=50052)
```

### Adding a new device

Any instrument class that accepts a `SilaClient` in its constructor can be connected the same way - see `instruments.py` for the `Gantry`/`PHProbe` pattern to follow:

```python
bench.connect("conductivity", ConductivitySensor, server="rxn-bench-conductivity")
bench.conductivity.read()
```

---

## API Reference

### `RxnBenchClient`

```python
RxnBenchClient(host: str = "localhost")
```

Use as a context manager (`with RxnBenchClient() as bench:`) to ensure connections and the experiment lock are released cleanly. Or call `bench.close()` manually.

| Method | Description |
|---|---|
| `connect(name, cls, *, server=None, host=None, port=None)` | Connect to a SiLA server and expose it as `bench.<name>`. Pass `server` for mDNS discovery, or `host`/`port` explicitly. |
| `at_well(well, stabilize=0.0)` | Context manager: move to well, engage tool, wait `stabilize` seconds, run body, disengage. Requires a connected `gantry`. |
| `check_pause_stop()` | Raise `ExperimentStopped` if the UI stop button was pressed; blocks while paused. Called automatically by `at_well()`. |
| `set_log_output(path, columns=None)` | Open a CSV file for `bench.log()`. |
| `log(**kwargs)` | Append one row (with timestamp, and current well if inside `at_well()`) to the log file. |
| `close()` | Release the experiment lock, close the log file, and close all instrument connections. |

### `Gantry` (`bench.connect("gantry", Gantry, ...)`)

| Method | Description |
|---|---|
| `load_workspace(name)` / `load_workspace_yaml(content=None)` | Load a workspace by name or raw YAML (`None` uses whatever is active on the server). |
| `list_workspaces()` | Returns `list[str]` of available workspace names. |
| `get_workspace_wells(plate_id=None, plate_grids=None)` | Returns `list[str]` of `"plate_id/well"` labels in the active workspace. |
| `set_toolhead(name)` / `confirm_toolhead_mounted()` / `mount_toolhead(name)` | Load toolhead geometry and mark it mounted (`mount_toolhead` does both). |
| `clear_toolhead_mounted()` / `list_toolheads()` | Mark detached / list `(name, display_name)` pairs. |
| `move_to(x, y, z)` / `move_to_well(label)` / `jog(dx, dy, dz)` | Motion commands. |
| `engage_tool(depth=None)` / `disengage_tool(depth=None)` | Defaults to the toolhead's configured `z_engage`. |
| `get_position()` | Returns `(x, y, z)` tuple. |
| `save_and_park()` | Park carriage and persist homing state. |

### `PHProbe` (`bench.connect("ph", PHProbe, ...)`)

| Method | Description |
|---|---|
| `read()` | Single pH reading. |
| `read_avg(n=5, interval=1.0)` | Average of `n` readings, `interval` seconds apart. |
| `read_stable()` | Uses a Regression Slope model to find a stable reading over a floating window. |
| `wait_for(*, above=None, below=None, timeout=300.0, interval=5.0)` | Block until pH crosses a threshold. |
| `calibrate(point, value)` | Calibrate at `"low"`/`"mid"`/`"high"` with a known buffer `value`. |
| `set_temperature(celsius)` | Set temperature compensation (deg C) applied to pH readings. |

---

## How Scripts Get to the Backend

The client is a library meant to be imported in scripts that run **on the backend machine** (a Raspberry Pi in the reference deployment, or a machine on the same network as the backend host). Options for deploying scripts:

- **`scp`** - copy the script file and run it over SSH
- **Git pull** - keep experiment scripts in a repo and pull on the backend
- **Script Runner SiLA service** - a planned future device package that accepts a script as a string and runs it server-side

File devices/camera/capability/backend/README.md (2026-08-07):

# rxn-bench-camera

SiLA2 server for the camera capability: streams periodic still images as a `LatestImage` observable property and archives each capture to disk. Hardware-agnostic - actual image capture happens through whichever driver is registered (reference driver: `rxn-bench-crowsnest-camera-driver`, a Crowsnest-managed webcam stream - see [../../driver/README.md](../../driver/README.md)). Runs as an independent process on the device host alongside `rxn-bench-gantry`/`rxn-bench-ph`.

**Port:** 50053
**SiLA UUID:** `c100b376-f1f2-4c63-986d-448e0fdf0f57`

---

## Requirements

- Python 3.10+
- [`uv`](https://docs.astral.sh/uv/) - install with `curl -LsSf https://astral.sh/uv/install.sh | sh`
- **Real hardware only:** a webcam already streaming through [Crowsnest](https://github.com/mainsail-crew/crowsnest) (or a compatible ustreamer/mjpg-streamer HTTP endpoint) on the same network
- Access to the UniteLabs private PyPI index (see `rxnbench/backend/pyproject.toml` for the index URL)

Install dependencies from the workspace root:

```bash
cd rxnbench/backend
uv sync
```

---

## Running

### Development (mock camera)

Returns a fixed placeholder image - no hardware or network needed:

```bash
cd rxnbench/backend
RXN_BENCH_MOCK=1 uv run rxn-bench-camera
```

### Real hardware

```bash
cd rxnbench/backend
uv run rxn-bench-camera
```

The server searches for a config file in this order:

1. `~/.rxn_bench/camera.json`
2. `configs/camera.json` (bundled default, relative to this package's own directory)

Pass an explicit config with `--config`:

```bash
uv run rxn-bench-camera --config /path/to/camera.json
```

---

## Configuration

`configs/camera.json` holds the SiLA server identity/port (same shape as every other device's config - see `sila_server.port`/`hostname`/`tls`).

Crowsnest connection settings live separately, in `~/.rxn_bench/machine.yaml` (shared with the gantry package's `moonraker_fallback_host` - both describe the same physical bench machine):

| Field | Default | Description |
|---|---|---|
| `crowsnest_base_url` | `http://sv08.local:8080` | Host:port Crowsnest's streamer is listening on |
| `crowsnest_snapshot_path` | `/snapshot` | HTTP path returning one JPEG frame (ustreamer's default; use e.g. `/webcam/?action=snapshot` for mjpg-streamer) |
| `capture_interval_s` | `30.0` | Seconds between captures - also runtime-adjustable via the `SetCaptureInterval` command |

Shorter intervals give more responsive live viewing at the cost of faster growth of `logs/images/` (each capture is archived - see below).

---

## SiLA Features

### `Camera`

**Observable Properties:**

| Property | Type | Description |
|---|---|---|
| `LatestImage` | `bytes` (SiLA Binary) | Most recently captured frame, JPEG-encoded. Streams a new value every `capture_interval_s`. |

**Commands:**

| Command | Parameters | Description |
|---|---|---|
| `SetCaptureInterval` | `Seconds: float` | Change how often `LatestImage` captures (and archives) a new frame. Must be positive. |

---

## Logging

Every capture is logged twice:

- `logs/<timestamp>.jsonl` - one line per capture (filename + size), auto-pruned after 30 days. Same append-only JSONL pattern as every other device's `session_log.py`.
- `logs/images/camera_<timestamp>.jpg` - the actual frame, auto-pruned after 7 days (`image_log.py`) since binary frames are far heavier than a log line. Tune `capture_interval_s` or `ImageLog`'s `max_days` if this doesn't fit the host's storage budget.

---

## Crowsnest Wiring

Crowsnest itself has no API - it is a process supervisor that launches a real streamer backend (ustreamer by default, sometimes mjpg-streamer) per camera defined in its own `crowsnest.conf` on the host running it (the SOVOL SV08's controller in the reference deployment). The driver package's `crowsnest_camera.py` talks straight to that streamer's plain HTTP snapshot route. If a bench's `crowsnest.conf` is configured for mjpg-streamer instead of the ustreamer default, override `crowsnest_snapshot_path` in `~/.rxn_bench/machine.yaml` (e.g. `/webcam/?action=snapshot`).

**Known gap:** the exact snapshot path has not yet been verified against a live SV08/Crowsnest deployment - confirm `crowsnest_base_url`/`crowsnest_snapshot_path` on a real bench before relying on the non-mock path.

---

## Adding a Different Camera Source

`server.py` never imports a concrete driver - it asks an entry-point registry for whichever name `RXN_BENCH_CAMERA_DRIVER` names (default: `crowsnest`). A different camera source plugs in with **no changes to this package**:

1. In a new package, implement a class/factory satisfying `CameraProtocol` (one method: `capture() -> bytes`):

   ```python
   # interfaces.py
   class CameraProtocol(Protocol):
       def capture(self) -> bytes: ...
   ```

2. Register a factory function under the `rxn_bench.camera_drivers` entry-point group in that package's `pyproject.toml` - see [`../../driver/backend/pyproject.toml`](../../driver/backend/pyproject.toml) for the exact shape.
3. Select it with `RXN_BENCH_CAMERA_DRIVER=<your-entry-point-name>`.

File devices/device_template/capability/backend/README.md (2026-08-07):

# device_template

Boilerplate for adding a new device to the rxn bench. Each device is a self-contained `devices/<name>/` folder, split into a `capability/{backend,frontend}` (the SiLA feature + widget - hardware-agnostic) and, if it has real vendor hardware, a `driver/` (see `docs/ai/CURRENT_STATE.md` §1 "Capability + driver split"). Copy this directory, rename everything marked `TODO`, and fill in your logic. The mock runs immediately - real hardware comes later.

This template only has a `capability/` - its mock is a generic stub, not real hardware, so there's nothing to split into a driver yet. If your device does have real hardware, see `devices/ph_sensor/` for the fullest worked example (driver package, wire-protocol mocks, hardware CAD, entry-point registration).

---

## Checklist

**1. Copy and rename the device folder**
```bash
# from the repo root
cp -r devices/device_template devices/my_device
```

**2. Rename `rxn_bench_template` -> `rxn_bench_mydevice` in the capability backend**
```bash
# In devices/my_device/capability/backend/:
mv src/rxn_bench_template src/rxn_bench_mydevice
grep -rl "rxn_bench_template\|mydevice\|MyDevice\|template" . \
  --include="*.py" --include="*.toml" --include="*.json" \
  | xargs sed -i 's/rxn_bench_template/rxn_bench_mydevice/g'
# Then rename classes by hand in interfaces.py, feature.py, mock_device.py, server.py
```

**3. Edit each capability backend file** - follow the `TODO` comments in order:

| File | What to change |
|---|---|
| `interfaces.py` | Rename `MyDeviceProtocol`; replace `read()` / `do_action()` with your hardware operations |
| `feature.py` | Rename `MyDevice`; rename `measurement` / `perform_action`; add/remove properties and commands |
| `mock_device.py` | Rename `MockMyDevice`; return realistic fixed values |
| `server.py` | If you have real hardware, add a driver package (see "Adding a driver" below) instead of initialising it inline |
| `_cli.py` | Set `_DEVICE_NAME` to your device's config filename stem |
| `configs/mydevice.json` | Rename file; set `port` (next available after 50054); generate a new UUID; update `name` and `description` |
| `pyproject.toml` | Rename `name`, `description`, entry point, and `packages` |

**4. Add the capability backend to the uv workspace**
```toml
# rxnbench/backend/pyproject.toml
[tool.uv.workspace]
members = [
    "../../devices/gantry/capability/backend",
    "../../devices/ph_sensor/capability/backend",
    "../../devices/my_device/capability/backend",
    "client",
]
```

**5. Wire up the frontend device plugin**

`devices/my_device/capability/frontend/` already exists (copied in step 1), with the same shape as `devices/gantry/capability/frontend/` and `devices/ph_sensor/capability/frontend/`:

```text
devices/my_device/capability/frontend/
  pyproject.toml                              <- declares the "rxn_bench.devices" entry point
  src/rxn_bench_mydevice_frontend/
    __init__.py             <- exports FEATURE_FRAGMENTS + create_widget()
    connection_spec.yaml    <- manifest: streams/commands this feature exposes
    generated_connection.py <- generated boilerplate, do not hand-edit
    connection.py           <- handwritten subclass: decode handlers, convenience methods
    widget.py                <- handwritten Qt widget
```

It's discovered via a Python entry point, not a config file to edit by hand:

1. Rename the package (`src/rxn_bench_device_template_frontend/` -> `src/rxn_bench_mydevice_frontend/`) and update `pyproject.toml`'s `name`, `packages`, and `[project.entry-points."rxn_bench.devices"]` line (`device_template = "..."` -> `my_device = "rxn_bench_mydevice_frontend"`).
2. Add it to `rxnbench/frontend/pyproject.toml`, mirroring the existing devices - one line in `dependencies` (`"rxn-bench-my-device-frontend"`) and one in `[tool.uv.sources]` (`rxn-bench-my-device-frontend = { path = "../../devices/my_device/capability/frontend", editable = true }`). `uv sync` from `rxnbench/frontend/` then installs it and `rxn_bench_ui.devices.all_devices()` picks it up automatically - no core code to edit.
3. `__init__.py` follows the same contract: a `FEATURE_FRAGMENTS: list[str]` matched against advertised SiLA feature identifiers, and `create_widget(server, theme) -> QWidget`. Rename the fragments and widget class.
4. Add your device to `_DEVICES` in `rxnbench/backend/scripts/gen_proto.py` and run `make gen-proto` (from `rxnbench/backend`) to generate the protobuf stubs. Then update `connection_spec.yaml` and regenerate the connection boilerplate from `rxnbench/frontend/`:

   ```bash
   make gen-connections   # regenerates every device's generated_connection.py from its connection_spec.yaml
   ```

5. `connection.py` subclasses the generated base and adds decode handlers/convenience methods by hand. `widget.py` is fully handwritten - never generated (see `CLAUDE.md`).
6. If you don't need a custom widget yet, you can delete `devices/my_device/capability/frontend/` entirely: unrecognized servers fall back to the generic `GenericDeviceWidget`. (There's also a zero-setup drop-in path with no `pyproject.toml`/entry point at all - a flat `devices/my_device/frontend/__init__.py` - still supported as a fallback for quick experiments, but the entry-points shape above is what ships for real.)

**6. Run the mock to verify everything wires up**
```bash
cd rxnbench/backend
make install   # uv sync + aggregate_toolheads.py
RXN_BENCH_MOCK=1 uv run --package rxn-bench-mydevice rxn-bench-mydevice
```

**7. Add an instrument class to `rxn-bench-client`**
```python
# rxnbench/backend/client/src/rxn_bench_client/instruments.py
class MyDevice:
    def __init__(self, sila: SilaClient) -> None:
        self._d = sila

    def read(self) -> float:
        return _once(self._d.MyDevice.Measurement)
```
Export it from `rxnbench/backend/client/src/rxn_bench_client/__init__.py`, then use it like the built-in instruments:
```python
bench.connect("mydevice", MyDevice, server="rxn-bench-mydevice")
bench.mydevice.read()
```

---

## Adding a driver (only if you have real hardware)

Once `mock_device.py` isn't enough and you're wiring up an actual instrument, don't put the vendor-specific code in `capability/backend/` - give it its own `devices/my_device/driver/backend/` package instead, so the capability stays hardware-agnostic and reusable:

1. Implement a class/factory satisfying your `interfaces.py` Protocol in the new driver package.
2. Register a factory function under a new `rxn_bench.mydevice_drivers` entry-point group in the driver package's `pyproject.toml`.
3. In `capability/backend/src/rxn_bench_mydevice/server.py`, load it via `importlib.metadata.entry_points(group="rxn_bench.mydevice_drivers")` instead of importing it directly - see `devices/ph_sensor/capability/backend/src/rxn_bench_ph/server.py` for the exact pattern (it also shows the `RXN_BENCH_MOCK=1` short-circuit staying capability-side).
4. Add the driver package to the uv workspace's `[tool.uv.sources]` as a plain editable path dependency of the capability package - **not** a separate `[tool.uv.workspace] members` entry (a real uv limitation with reciprocal `{workspace = true}` sources - see `docs/ai/CURRENT_STATE.md` §1).

`devices/ph_sensor/` is the fullest worked example: two transports, wire-protocol mocks, hardware CAD (`driver/hardware_models/`), and a gantry toolhead config (`driver/toolhead/`).

---

## Generating a new UUID

```bash
python3 -c "import uuid; print(uuid.uuid4())"
```

Each device must have a unique UUID in its config. Never reuse the template UUID.

---

## File structure reference

```
devices/my_device/
  capability/
    backend/
      src/rxn_bench_mydevice/
        __init__.py          <- empty, leave as-is
        interfaces.py        <- Protocol (hardware contract)
        feature.py           <- SiLA feature (CDK decorators)
        mock_device.py       <- in-memory mock for dev/testing
        server.py            <- create_app() factory; loads a driver via entry points if you have one
        _cli.py               <- entry point
      configs/
        mydevice.json        <- SiLA server identity and port
      tests/
        __init__.py
        test_mock_device.py  <- starter tests, add more
      pyproject.toml
      README.md
    frontend/
      pyproject.toml           <- declares the "rxn_bench.devices" entry point
      src/rxn_bench_mydevice_frontend/
        __init__.py             <- FEATURE_FRAGMENTS + create_widget()
        connection_spec.yaml    <- manifest for gen_connections.py
        generated_connection.py <- generated, do not hand-edit
        connection.py           <- handwritten decode handlers/convenience methods
        widget.py                <- handwritten Qt widget
  driver/                       <- only if you have real hardware - see "Adding a driver" above
    backend/
      src/rxn_bench_<vendor>_driver/
      pyproject.toml            <- declares a "rxn_bench.mydevice_drivers" entry point
    hardware_models/            <- CAD for this device's hardware, if any
    toolhead/                   <- gantry toolhead config, if this device mounts on the gantry
```

`devices/ph_sensor/` is the canonical real-world example of this pattern, including the driver split.

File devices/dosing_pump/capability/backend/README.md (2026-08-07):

# rxn-bench-dosing-pump

SiLA2 server for the dosing pump capability. Hardware-agnostic - actual dispensing happens through whichever driver is registered (reference driver: `rxn-bench-atlas-ezo-pmp-driver`, an Atlas Scientific EZO-PMP over UART - see [../../driver/README.md](../../driver/README.md)). Runs on port 50054.

## Layout

```text
src/rxn_bench_dosing_pump/
├── server.py       <- create_app(); loads the registered driver via entry points
├── _cli.py         <- rxn-bench-dosing-pump entry point
├── feature.py      <- DosingPump SiLA feature
├── interfaces.py   <- DosingPumpProtocol (hardware contract)
└── session_log.py  <- append-only JSONL event log
```

The Atlas EZO-PMP driver (`atlas_dosing_pump.py`, `ezo_pmp_commands.py`, `atlas_scientific_uart_driver.py`, `mock_uart.py`, `mock_device.py`) lives in the separate `../../driver/backend/src/rxn_bench_atlas_ezo_pmp_driver/` package, registered under the `rxn_bench.dosing_pump_drivers` entry-point group - this package never imports it directly. Its layering mirrors `rxn_bench_atlas_ezo_ph_driver`: a transport-agnostic command set plus one transport class. That structure is duplicated rather than shared on purpose - the two drivers share a *vendor protocol family*, not a command set, and per `docs/ai/CURRENT_STATE.md` §8 driver packages stay independently deployable.

Note: `RXN_BENCH_MOCK=1`'s simulated pump (`MockDosingPump`) is itself provided by the driver package, registered as a second entry point (`atlas_ezo_pmp_mock`) - it's built on the real Atlas driver stack over a protocol emulator rather than a generic stub, so it exercises the same command encoding the bench uses. See `../../driver/backend/src/rxn_bench_atlas_ezo_pmp_driver/mock_device.py`.

## Running

```bash
# Mock (no hardware; dispensing is simulated against the wall clock)
RXN_BENCH_MOCK=1 uv run --package rxn-bench-dosing-pump rxn-bench-dosing-pump

# Real hardware (from rxnbench/backend)
make start-pump

# Tests
make test-pump
```

### Environment

| Variable | Default | Meaning |
| --- | --- | --- |
| `RXN_BENCH_MOCK` | unset | `1` uses the simulated pump |
| `RXN_BENCH_PUMP_SERIAL_PORT` | `/dev/serial0` | Serial device for the EZO-PMP |
| `RXN_BENCH_PUMP_BAUD` | `9600` | EZO UART default |

> **Serial port contention:** the bench's EZO-pH already owns `/dev/serial0`. Give the pump its own UART (`dtoverlay=uartN` in `/boot/firmware/config.txt`) or a USB-serial adapter and set `RXN_BENCH_PUMP_SERIAL_PORT`, or the two will fight over the same bytes. On the reference Pi 5, `dtoverlay=uart2` brings up UART2 on GPIO4/5 as `/dev/ttyAMA2` - confirmed against real EZO-PMP hardware 2026-08-04. `install_service.sh` sets `RXN_BENCH_PUMP_SERIAL_PORT=/dev/ttyAMA2` for the `pump` service automatically.

## SiLA surface

**Observable properties** - `VolumeDispensed` (ml, polled 1 Hz), `Dispensing` (bool).

**Unobservable properties** - `TotalVolume`, `AbsoluteTotalVolume`, `PumpVoltage`, `MaxFlowRate`, `Paused`, `Inverted`.

**Commands** - `Dispense`, `DoseOverTime`, `DispenseContinuously`, `SetFlowRate`, `Stop` (returns the volume delivered), `SetPaused`, `SetInverted`, `ClearTotalVolume`, `Calibrate`, `ClearCalibration`, `GetCalibrationStatus`.

Dispense commands return as soon as the pump accepts them; the pump keeps running. Watch `Dispensing` to know when a dose is actually finished.

### Driver-only commands (not on the SiLA feature)

`find()`, `set_led()`/`get_led()`, `sleep()`/`wake()`, and `set_protocol_lock()`/`get_protocol_lock()` exist on the driver and `AtlasDosingPump` but are deliberately not exposed over SiLA - they identify or power-manage the *circuit* rather than dose liquid. This matches `rxn_bench_ph`, which keeps the same group driver-level only.

- `find()` blinks the LED to tell this circuit apart from the pH one on the same bench. Per the datasheet it also disables continuous reporting - harmless, since the driver already turns that off at startup.
- `sleep()` drops the control system from ~13.4 mA to ~0.415 mA at 5 V. It does **not** cut the 12-24 V motor supply, so it is not a way to make the pump safe to handle.
- **`wake()` is required after `sleep()`.** The byte that wakes a sleeping EZO is consumed doing so and is not executed - the circuit replies `*WA` instead of the expected answer, so the command is silently lost. `wake()` absorbs that throwaway exchange; without it, the first command after sleeping fails with a timeout. `MockEZOPumpUart` reproduces this, so the path is tested rather than assumed.

Deliberately **not** implemented: `Baud`, `Factory`, `Name`, and the I2C-mode switch (they reconfigure the circuit in ways that can strand the connection mid-run), `O` (enable/disable output parameters - it changes the output string format that `R` parsing depends on), and `Dstart` (dispense-at-startup makes the pump run on power-up without a client, working against having the bench drive it).

## Protocol notes worth knowing

- **`*DONE` is both a reply and an interrupt.** It is the only response to `X` (stop), *and* it arrives unsolicited whenever a dispense finishes on its own. The driver treats it as a reply only when the command in flight expects one (`done_terminates`); otherwise it is recorded in `last_completed_volume` and skipped, so a dose completing mid-query can't corrupt an unrelated reading.
- **`P` and `Invert` are toggles.** `AtlasDosingPump.set_paused` / `set_inverted` read the current state first, so callers can assert a desired state instead of tracking parity.
- **Rejections aren't plain `*ER`.** `*MINVOL` (below the 0.5 ml minimum) and `*TOOFAST` (above the calibrated maximum) are raised as `ValueError` with the cause spelled out.
- **Continuous reporting is disabled at startup** (`C,0`), like the pH driver, so reads stay clean request/response.
- Every command uses a uniform 300 ms processing delay - unlike the EZO-pH, where reads need 900 ms.
- **`MaxFlowRate` is not the pump's top speed.** `DC,?` reports the fastest rate the pump can *regulate* to in constant-rate mode (datasheet example: 58.5 ml/min, "determined after calibration"). Continuous dispensing (`D,*`) bypasses regulation and runs open-loop at ~105 ml/min - the cover spec's figure. `MockEZOPumpUart` keeps the two separate: `max_flow_rate` (default 58.5) gates `DC`, while `_CONTINUOUS_RATE` (105) drives `D,*`. To run continuously at a *chosen* rate, use `DC,[rate],*` - Continuous takes no rate argument.

## Calibration

Single-point, against the volume actually delivered:

1. `Dispense(10)` into a graduated container.
2. Measure what really came out, e.g. 9.4 ml.
3. `Calibrate(9.4)`.

`GetCalibrationStatus` returns 0 uncalibrated, 1 fixed volume, 2 volume-over-time, 3 both. `MaxFlowRate` is only meaningful once the pump is calibrated.

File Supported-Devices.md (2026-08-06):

# Supported devices registry

Rxn Bench splits each device into a **capability** (a SiLA feature + Protocol
interface + Qt widget, hardware-agnostic) and one or more **drivers** (a
concrete implementation of that capability's Protocol, registered under a
`rxn_bench.<capability>_drivers` entry-point group). A driver also owns
anything specific to its physical product: the vendor's wire protocol, its
hardware CAD (`hardware_models/`), and its toolhead config if it mounts on
the gantry. See [docs/ai/CURRENT_STATE.md](docs/ai/CURRENT_STATE.md) §1-2 for
the full architecture writeup.

This table is the index: which capability a driver plugs into, and which
repo each half lives in (`devices/<name>/{capability,driver}` in this
checkout - currently git submodules pointing at local paths pending GitHub
hosting).

| Capability | Package | Driver | Package | Entry point | Hardware |
| --- | --- | --- | --- | --- | --- |
| Gantry (motion) | `rxn-bench-gantry` | Moonraker/Klipper | `rxn-bench-moonraker-driver` | `moonraker` | SOVOL SV08 3D printer |
| pH sensing | `rxn-bench-ph` | Atlas Scientific EZO-pH | `rxn-bench-atlas-ezo-ph-driver` | `atlas_ezo` (I2C or UART) | Atlas Scientific EZO-pH circuit + Spear Tip probe |
| Camera | `rxn-bench-camera` | Crowsnest webcam stream | `rxn-bench-crowsnest-camera-driver` | `crowsnest` | Any Crowsnest-managed USB webcam |
| Dosing pump | `rxn-bench-dosing-pump` | Atlas Scientific EZO-PMP | `rxn-bench-atlas-ezo-pmp-driver` | `atlas_ezo_pmp` (+ `atlas_ezo_pmp_mock`) | Atlas Scientific EZO-PMP peristaltic pump |

Each capability is reusable beyond its current reference driver - a different
pH probe, camera, or dosing pump brand plugs in by adding a new driver
package that implements the same Protocol and registers under the same
entry-point group, with **zero changes** to the capability's feature, proto,
client, or Qt widget. `devices/device_template/capability/` is the reference
scaffold for a brand-new capability that doesn't fit any of the above; see
the `new-device` dev-agent skill for the checklist (existing-interface check
first, template copy only if it's a genuine misfit).

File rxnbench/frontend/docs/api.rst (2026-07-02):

API Reference
=============

App
---

.. automodule:: rxn_bench_ui.app
   :members:
   :undoc-members:
   :show-inheritance:

.. automodule:: rxn_bench_ui.discovery
   :members:
   :undoc-members:
   :show-inheritance:

.. automodule:: rxn_bench_ui.themes
   :members:
   :undoc-members:
   :show-inheritance:

Connections
-----------

.. automodule:: rxn_bench_ui.connections.base
   :members:
   :undoc-members:
   :show-inheritance:

Core UI
-------

.. automodule:: rxn_bench_ui.core.main_window
   :members:
   :undoc-members:
   :show-inheritance:

.. automodule:: rxn_bench_ui.core.server_browser
   :members:
   :undoc-members:
   :show-inheritance:

.. automodule:: rxn_bench_ui.core.device_registry
   :members:
   :undoc-members:
   :show-inheritance:

.. automodule:: rxn_bench_ui.core.experiment_panel
   :members:
   :undoc-members:
   :show-inheritance:

.. automodule:: rxn_bench_ui.core.experiment_notes
   :members:
   :undoc-members:
   :show-inheritance:

.. automodule:: rxn_bench_ui.core.csv_viewer
   :members:
   :undoc-members:
   :show-inheritance:

.. automodule:: rxn_bench_ui.core.generic_device
   :members:
   :undoc-members:
   :show-inheritance:

Gantry Device Plugin
--------------------

.. automodule:: rxn_bench_ui.devices.gantry
   :members:
   :undoc-members:
   :show-inheritance:

.. automodule:: rxn_bench_ui.devices.gantry.connection
   :members:
   :undoc-members:
   :show-inheritance:

.. automodule:: rxn_bench_ui.devices.gantry.widget
   :members:
   :undoc-members:
   :show-inheritance:

.. automodule:: rxn_bench_ui.devices.gantry.homing_dialog
   :members:
   :undoc-members:
   :show-inheritance:

.. automodule:: rxn_bench_ui.devices.gantry.toolhead_calibration_dialog
   :members:
   :undoc-members:
   :show-inheritance:

.. automodule:: rxn_bench_ui.devices.gantry.workspace_loader
   :members:
   :undoc-members:
   :show-inheritance:

pH Sensor Device Plugin
-----------------------

.. automodule:: rxn_bench_ui.devices.ph_sensor
   :members:
   :undoc-members:
   :show-inheritance:

.. automodule:: rxn_bench_ui.devices.ph_sensor.connection
   :members:
   :undoc-members:
   :show-inheritance:

.. automodule:: rxn_bench_ui.devices.ph_sensor.widget
   :members:
   :undoc-members:
   :show-inheritance:

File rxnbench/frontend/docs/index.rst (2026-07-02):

rxn-bench-ui
============

PySide6 desktop control UI for the Ames Lab automated chemistry bench.
Discovers SiLA2 servers on the local network via mDNS and loads a device
plugin panel for each recognised server.

.. toctree::
   :maxdepth: 2
   :caption: Contents

   api

Indices
-------
* :ref:`genindex`
* :ref:`modindex`

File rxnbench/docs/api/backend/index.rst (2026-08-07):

Backend client  (``rxn_bench_client``)
======================================

Python client library for driving the SiLA2 device servers over gRPC - the
motion platform, pH sensor, and camera Features exposed by the Raspberry Pi
device backends.

.. autosummary::
   :toctree: generated
   :recursive:

   rxn_bench_client

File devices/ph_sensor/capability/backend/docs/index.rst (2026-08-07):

rxn-bench-ph
============

SiLA2 pH sensor server for the Ames Lab automated chemistry bench.
Drives an Atlas Scientific EZO-pH circuit over I2C or UART and exposes
readings and calibration as gRPC calls via the UniteLabs CDK.

.. toctree::
   :maxdepth: 2
   :caption: Contents

   api

Indices
-------
* :ref:`genindex`
* :ref:`modindex`

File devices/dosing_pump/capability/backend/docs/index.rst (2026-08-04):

rxn-bench-dosing-pump
=====================

SiLA2 device server for the Atlas Scientific EZO-PMP peristaltic dosing pump
on the Ames Lab rxn bench. Supports volume dispensing, dose over time,
constant flow rate, and continuous dispensing over the EZO UART protocol.

.. toctree::
   :maxdepth: 2
   :caption: Contents

   api

Indices
-------
* :ref:`genindex`
* :ref:`modindex`

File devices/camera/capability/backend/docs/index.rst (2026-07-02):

rxn-bench-template
==================

Skeleton package for new SiLA2 device servers on the Ames Lab rxn bench.
Copy this package, rename it, and fill in the hardware-specific logic in
``feature.py`` and ``interfaces.py``.

.. toctree::
   :maxdepth: 2
   :caption: Contents

   api

Indices
-------
* :ref:`genindex`
* :ref:`modindex`

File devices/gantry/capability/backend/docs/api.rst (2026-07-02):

API Reference
=============

.. automodule:: rxn_bench_gantry.feature
   :members:
   :undoc-members:
   :show-inheritance:

.. automodule:: rxn_bench_gantry.controller
   :members:
   :undoc-members:
   :show-inheritance:

.. automodule:: rxn_bench_gantry.interfaces
   :members:
   :undoc-members:
   :show-inheritance:

.. automodule:: rxn_bench_gantry.motion_engine
   :members:
   :undoc-members:
   :show-inheritance:

.. automodule:: rxn_bench_gantry.homing_manager
   :members:
   :undoc-members:
   :show-inheritance:

.. automodule:: rxn_bench_gantry.homing_state
   :members:
   :undoc-members:
   :show-inheritance:

.. automodule:: rxn_bench_gantry.toolhead_manager
   :members:
   :undoc-members:
   :show-inheritance:

.. automodule:: rxn_bench_gantry.toolhead_config
   :members:
   :undoc-members:
   :show-inheritance:

.. automodule:: rxn_bench_gantry.workspace_manager
   :members:
   :undoc-members:
   :show-inheritance:

.. automodule:: rxn_bench_gantry.workspace_config
   :members:
   :undoc-members:
   :show-inheritance:

.. automodule:: rxn_bench_gantry.plate_geometry
   :members:
   :undoc-members:
   :show-inheritance:

.. automodule:: rxn_bench_gantry.moonraker_client
   :members:
   :undoc-members:
   :show-inheritance:

.. automodule:: rxn_bench_gantry.moonraker_discovery
   :members:
   :undoc-members:
   :show-inheritance:

.. automodule:: rxn_bench_gantry.mock_moonraker
   :members:
   :undoc-members:
   :show-inheritance:

.. automodule:: rxn_bench_gantry.machine_config
   :members:
   :undoc-members:
   :show-inheritance:

.. automodule:: rxn_bench_gantry.errors
   :members:
   :undoc-members:
   :show-inheritance:

.. automodule:: rxn_bench_gantry.session_log
   :members:
   :undoc-members:
   :show-inheritance:

.. automodule:: rxn_bench_gantry.server
   :members:
   :undoc-members:
   :show-inheritance:

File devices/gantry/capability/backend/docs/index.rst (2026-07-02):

rxn-bench-gantry
================

SiLA2 gantry motion-platform server for the Ames Lab automated chemistry bench.
Runs on the Raspberry Pi, communicates with Moonraker/Klipper over HTTP,
and exposes motion commands as gRPC calls via the UniteLabs CDK.

.. toctree::
   :maxdepth: 2
   :caption: Contents

   api

Indices
-------
* :ref:`genindex`
* :ref:`modindex`

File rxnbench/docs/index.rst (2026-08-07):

Automated Rxn Bench
====================

Software documentation for the Ames National Lab automated chemistry bench -
a Sovol SV08 CoreXY motion platform controlled via SiLA2 RPC from a Raspberry
Pi, with a PySide6 desktop client for interactive control.

.. toctree::
   :maxdepth: 1
   :caption: Components

   api/backend/index
   api/frontend/index

.. toctree::
   :maxdepth: 1
   :caption: Reference

   genindex
   modindex

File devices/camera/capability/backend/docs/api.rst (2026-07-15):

API Reference
=============

.. automodule:: rxn_bench_camera.feature
   :members:
   :undoc-members:
   :show-inheritance:

.. automodule:: rxn_bench_camera.interfaces
   :members:
   :undoc-members:
   :show-inheritance:

.. automodule:: rxn_bench_camera.crowsnest_camera
   :members:
   :undoc-members:
   :show-inheritance:

.. automodule:: rxn_bench_camera.mock_camera
   :members:
   :undoc-members:
   :show-inheritance:

.. automodule:: rxn_bench_camera.camera_config
   :members:
   :undoc-members:
   :show-inheritance:

.. automodule:: rxn_bench_camera.image_log
   :members:
   :undoc-members:
   :show-inheritance:

.. automodule:: rxn_bench_camera.session_log
   :members:
   :undoc-members:
   :show-inheritance:

.. automodule:: rxn_bench_camera.server
   :members:
   :undoc-members:
   :show-inheritance:

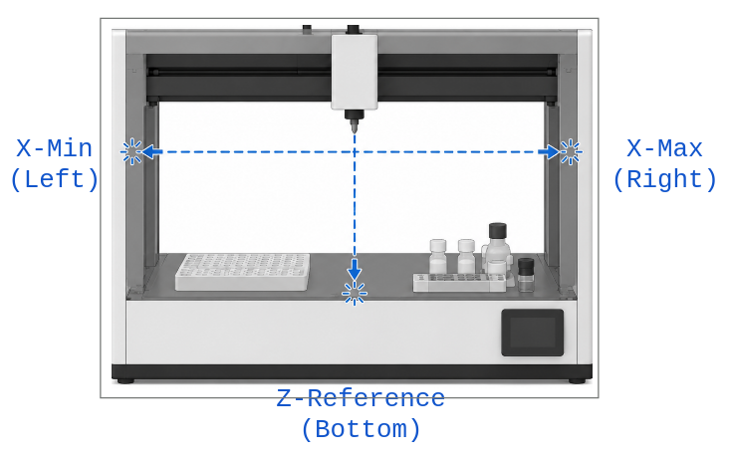
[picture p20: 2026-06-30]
devices/gantry/capability/frontend/src/rxn_bench_gantry_frontend/assets/gantry_home_XZ.png

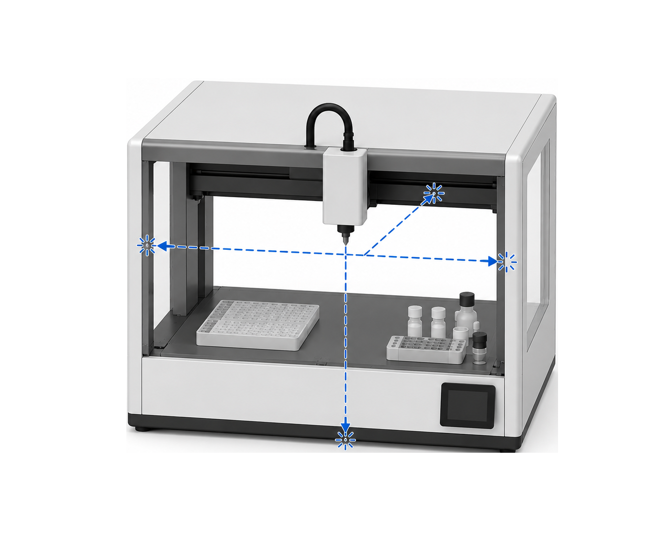
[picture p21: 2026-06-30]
devices/gantry/capability/frontend/src/rxn_bench_gantry_frontend/assets/gantry_home_reference.png

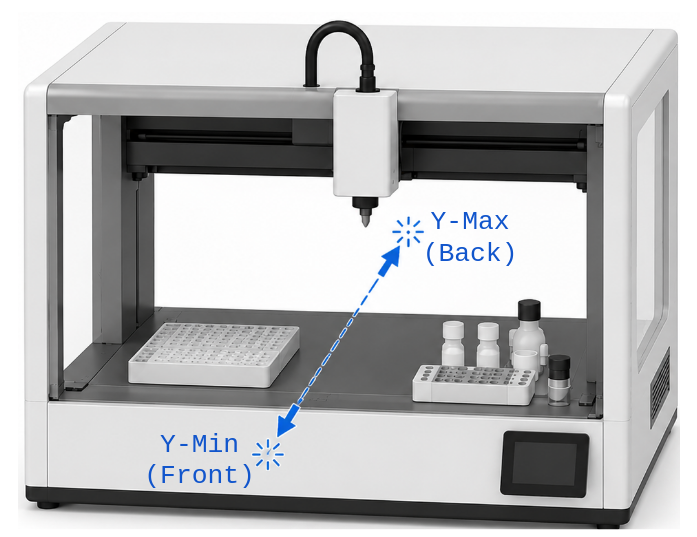
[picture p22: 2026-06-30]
devices/gantry/capability/frontend/src/rxn_bench_gantry_frontend/assets/gantry_home_Y.png

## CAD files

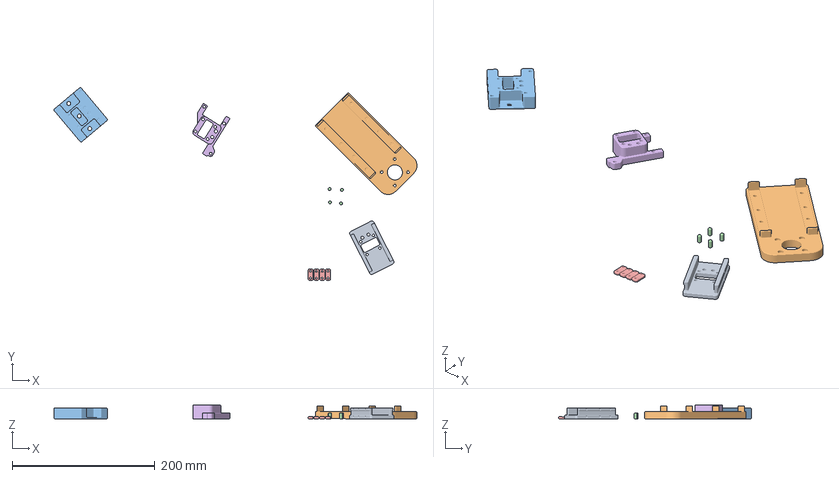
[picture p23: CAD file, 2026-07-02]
devices/gantry/driver/hardware_models/Toolhead Mount For MGN12 Carriage.3mf
508.0 x 269.7 x 19.1 mm
Toolhead Mount wMagnets For MGN12 Carriage.stl
Two-Head Base Board.stl
SV08 Big Boy Mounting Bracket.stl
Assembly x 2
SOVOL-SV08 Mounting Bracket.stl

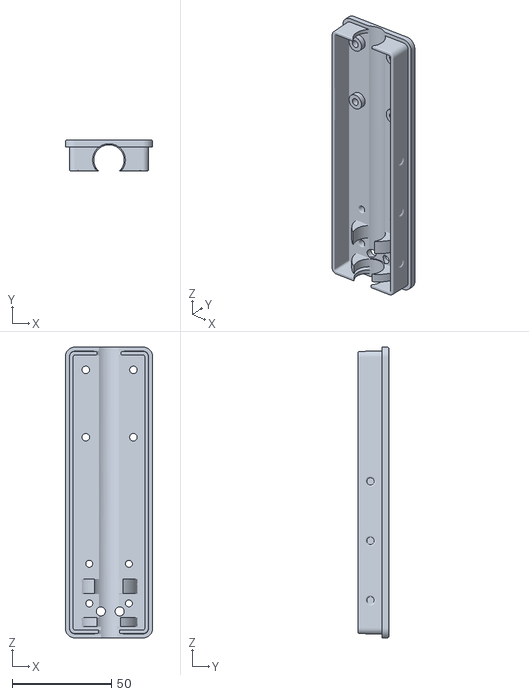
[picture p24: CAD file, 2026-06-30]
devices/ph_sensor/driver/hardware_models/pH Probe Mount.stl
44.1 x 15.5 x 146.8

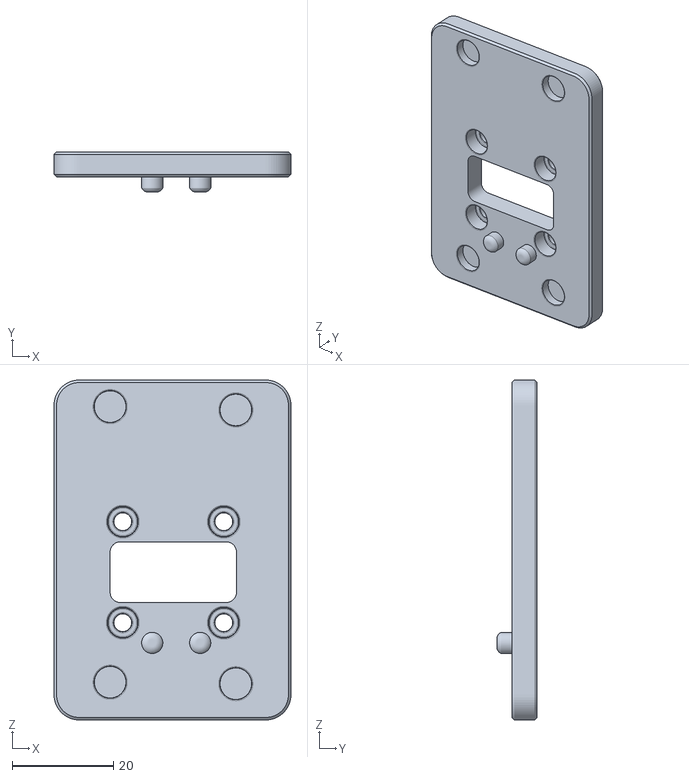
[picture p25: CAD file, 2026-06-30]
devices/gantry/driver/hardware_models/Mounting Plate.stl
46.9 x 8.00 x 67.3

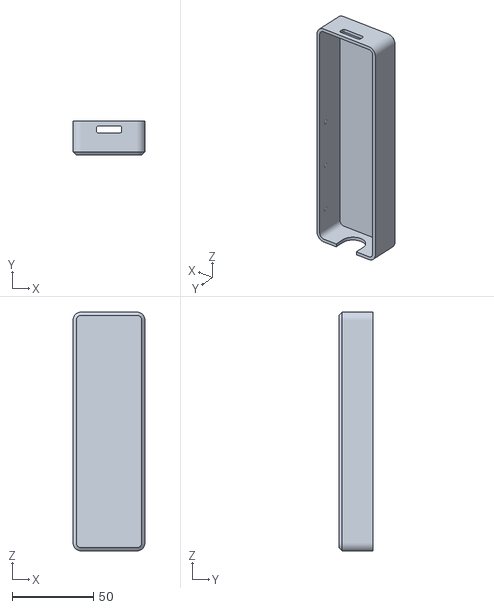
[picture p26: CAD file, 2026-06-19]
devices/ph_sensor/driver/hardware_models/pH Probe Lid.stl
44.1 x 21.0 x 146.8

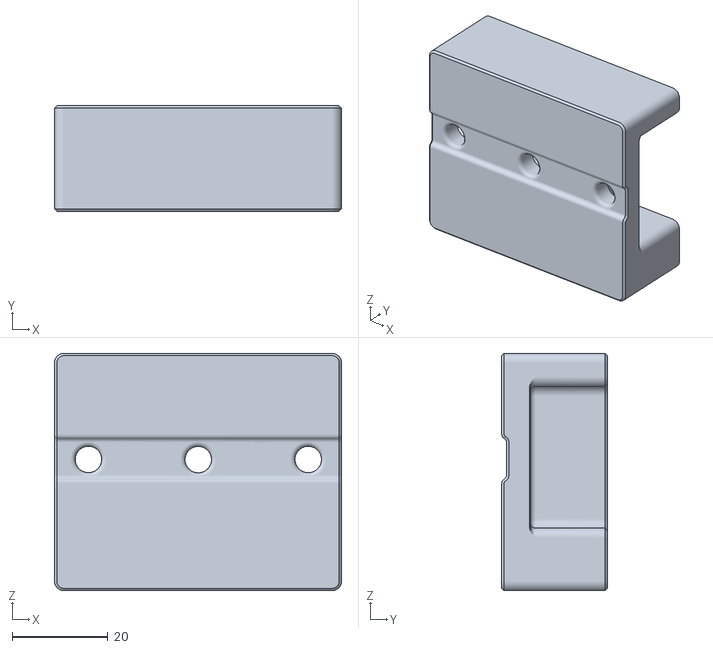
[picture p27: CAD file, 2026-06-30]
devices/gantry/driver/hardware_models/SOVOL-SV08 Big Boy Mounting Bracket.stl
59.8 x 22.0 x 49.5

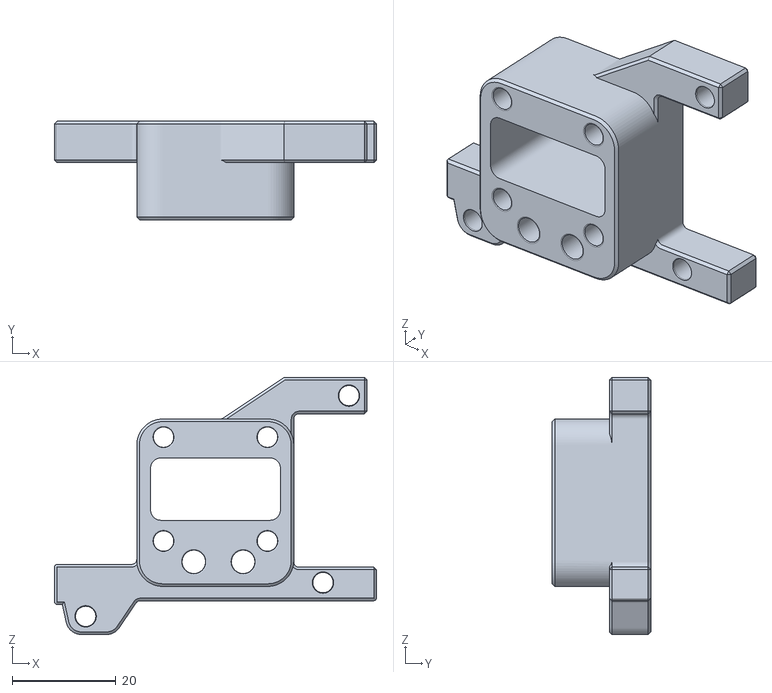
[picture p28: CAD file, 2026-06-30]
devices/gantry/driver/hardware_models/SOVOL-SV08 Mounting Bracket.stl
62.0 x 19.0 x 49.5

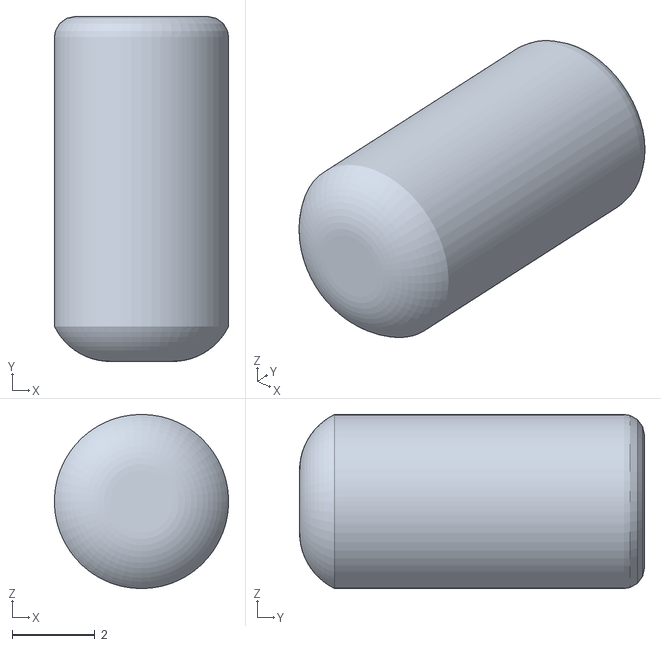
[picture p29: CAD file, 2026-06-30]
devices/gantry/driver/hardware_models/Mount Pin.stl
4.20 x 8.32 x 4.20

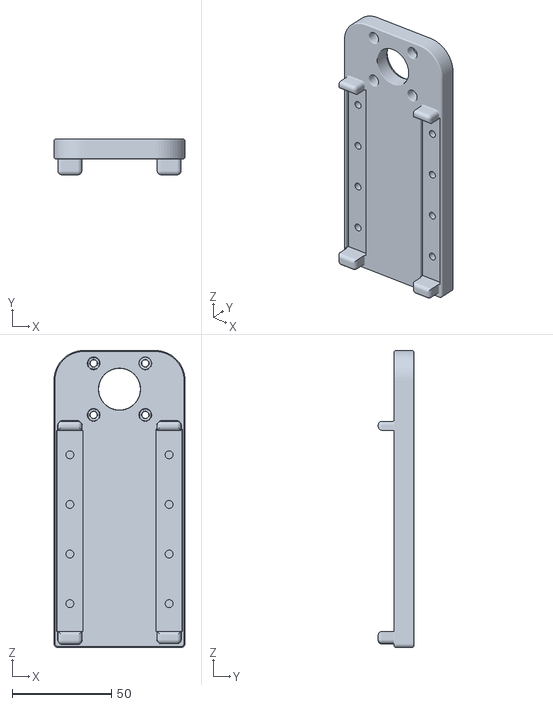
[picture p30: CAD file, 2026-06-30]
devices/gantry/driver/hardware_models/Two-Head Base Board.stl
66.0 x 18.0 x 149.6

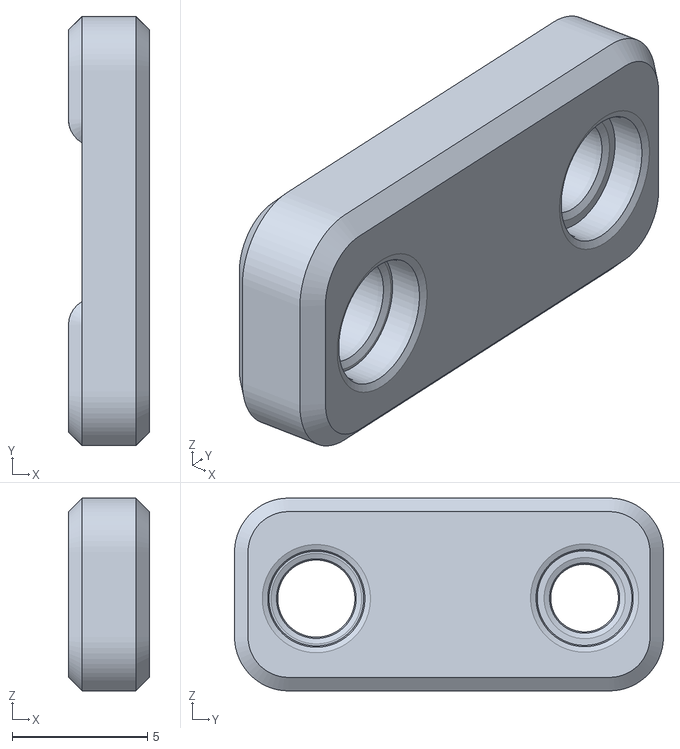
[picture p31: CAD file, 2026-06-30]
devices/gantry/driver/hardware_models/Belt Clamp.stl
3.00 x 15.9 x 7.13

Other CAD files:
devices/gantry/driver/hardware_models/Toolhead Mount For MGN12 Carriage.stl

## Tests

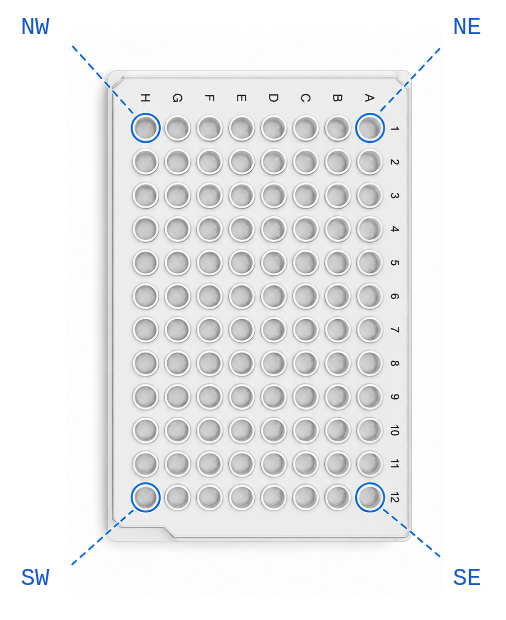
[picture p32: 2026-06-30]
devices/gantry/capability/frontend/src/rxn_bench_gantry_frontend/assets/toolhead_calibration_reference.png

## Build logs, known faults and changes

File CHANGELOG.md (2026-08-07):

# Changelog

All notable changes to Rxn Bench are recorded here.

## [Unreleased]

### Added

- `client` (2026-08-07): `bench.devices.<name>` auto-discovers and connects the four built-in instruments (`gantry`, `ph`, `camera`, `pump`) - no more `bench.connect(name, Class, server=...)` per instrument. First access scans the network once (via `sila2`'s built-in `SilaDiscoveryBrowser`, which already probes every discovered server's advertised SiLA features - no custom mDNS/gRPC code needed) and caches the result on the client, so later `bench.devices.<other>` accesses on the same session are instant. Zero matches or more than one matching server raises a clear error naming the feature and suggesting `bench.connect(...)` to disambiguate. New `rxn_bench_client.devices` module (`DEVICE_REGISTRY`, `discover_sila_clients`, `DeviceNamespace`); `client.py`'s `connect()` had its post-connection logic (instrument tracking, lock acquisition) extracted into a shared `_attach()` so both paths behave identically and end up on `bench.<name>` either way - `bench.devices.gantry` and `bench.gantry` are the same instrument, and repeated access never reconnects/rewraps. `bench.devices.raw(feature_name)` is the escape hatch for anything not in the small built-in registry - the raw SiLA feature proxy, no wrapper class required, so nothing is ever forced to conform to a pre-made interface. Fully additive: `bench.connect(...)` is untouched and the two styles mix freely in the same script. Verified: 14 new tests (fake-discovery, no real network) plus a live smoke test against `make start-mock` (real mDNS discovery + feature matching, explicit `connect()` and `bench.devices` on the same session interoperate, `bench.devices.gantry is bench.gantry` holds).

### Fixed

- `client` (2026-08-06): `RxnBenchClient.close()` now parks a connected gantry (`save_and_park()`) before releasing the experiment lock unconditionally, whatever the reason the session is ending - normal script completion, a manual stop from the UI (`ExperimentStopped` propagating out of `check_pause_stop()`), or any unhandled exception. Previously this relied entirely on the script itself explicitly calling `bench.gantry.save_and_park()` at the end; a script killed mid-run (SIGINT from the Experiment Runner's Stop button, or a probe/motion failure) skipped it, leaving the gantry's saved homing state stale relative to wherever it actually stopped and requiring a manual re-home next session. `connect()` now tracks every wrapped instrument (not just the lock holder) so `close()` can find and park a connected gantry regardless of connection order; `save_and_park()` on a dead/nonexistent connection is swallowed so it can't strand the experiment lock. The explicit `bench.gantry.save_and_park()` call is no longer needed in scripts (removed from the usage examples in `client.py`/`instruments.py`) but calling it is still harmless.
- `client` (2026-08-06): `PHProbe.read_stable()` no longer raises `PHStabilityTimeout` (removed) when the probe fails to settle within `timeout` - it prints a warning with the best-effort reading (last valid value, final drift/range) and returns that instead. Previously an uncaught timeout on any single well or calibration point crashed the whole run (`pH_calibrate_and_sample.py`, `calibrate_ph.py`, and both tutorial scripts all called `read_stable()` without a `try`/`except`) and lost every well after it; now a slow-to-settle well just gets logged and the run continues. Also fixes `pH_calibrate_and_sample.py`'s sample-well log rows silently dropping `settling_time` (it wasn't in the explicit `columns=` list passed to `set_log_output`, so `csv.DictWriter`'s `extrasaction="ignore"` was discarding it).

### Changed

- `client` (2026-08-06): `Gantry.shake()` now alternates axes round-robin (`axis` default `"y"` -> `"xy"`) and uses more, smaller bursts (`amplitude` 2.0mm -> 1.5mm, `cycles` 10 -> 12) instead of one long oscillation on a single axis - shorter, more frequent direction reversals across more than one axis flings droplets off more effectively. `axis` still accepts any combination of `"x"`/`"y"`/`"z"` (a single letter reproduces the old single-axis behavior); no SiLA/backend changes, this is client-side motion-pattern only (the Jog command has no speed parameter to tune).

- `devices` (2026-08-05): all 5 device frontends (gantry, ph_sensor, camera, dosing_pump, device_template) restructured from a flat `devices/<name>/frontend/*.py` tree into a pip-installable `src/rxn_bench_<name>_frontend/` package declaring a `rxn_bench.devices` entry point, matching the `src/` layout backend device packages already use. `rxn_bench_ui/devices/__init__.py`'s `all_devices()` now merges entry-point discovery with the previous `devices/*/frontend/` directory scan (kept as a zero-rebuild drop-in fallback for devices not packaged as a formal dependency). Each of the 10 device folders (5 frontend, 5 backend) is now also its own git repo, wired in as a submodule (`.gitmodules`) - first step towards a master-repo layout for the JOSS publication. `.gitmodules` currently points at local repo paths pending GitHub hosting. PyInstaller packaging (`rxn-bench-ui.spec`) now bundles the 5 device packages' code and entry-point metadata (`collect_all` + `copy_metadata`) at build time instead of staging their folders next to the executable; CI checkout steps gained `submodules: true`. Verified end-to-end: all 5 widgets construct via entry points both in dev and inside a real PyInstaller-frozen build (`make dist-check`), full backend + frontend test suites pass, `make check-proto`/`make check-connections` are clean.
- `devices` (2026-08-05): each backend device further split into a **capability** package (`rxn_bench_<name>` - SiLA feature, Protocol interface, hardware-agnostic generic mock) and a **driver** package (`rxn_bench_<vendor>_driver` - concrete vendor implementation, wire-protocol mocks, hardware CAD, toolhead config), the latter registered under a new `rxn_bench.<name>_drivers` entry-point group so no capability imports a concrete driver directly - the backend mirror of the frontend's entry-points plugin split. `devices/<name>/{capability,driver}` are each their own git repo/submodule (9 total: all 4 real devices have both, device_template only has capability - no real driver to split out). New `rxnbench/backend/scripts/aggregate_toolheads.py` (wired into `make install`/`install_offline.sh`) copies each driver's toolhead config (e.g. the pH probe's mount/engage geometry) into gantry's bundled `toolheads/` directory at install time, since gantry doesn't own device-specific toolhead data but does need it in its own package to load. Also fixes `install_service.sh`, `build_offline_bundle.sh`, and both Makefiles' proto/connection-spec glob paths for the new nesting, and switches CI's backend job to `make install` (was a bare `uv sync`, silently skipping the toolhead aggregation). Verified end-to-end: full backend test suite (capability + driver tests, all 4 devices), `check-proto`, full frontend suite, `check-connections`, and a real PyInstaller-frozen build (`make dist-check`) constructing all 5 device widgets. Not re-verified: an actual offline-bundle build + from-scratch Pi install (see CURRENT_STATE.md gap).

## [v0.1.5] - 2026-08-05

Packaged install now ships example scripts and workspace templates, results logging no longer silently overwrites a previous run, and a new 24-well 5mL rack labware/workspace update.

### Added

- `frontend` (2026-08-05): packaging now stages `Scripts/` and `Workspaces/` folders next to the built executable (`packaging/copy_workflows.py`, mirroring the existing `copy_device_plugins.py` pattern) - `Scripts/` from `rxnbench/backend/client/scripts/`, `Workspaces/` from the gantry's `workspace/definitions/*.yaml`. The Experiment Runner's "Browse" dialog and the gantry plugin's "Import Workspace YAML" dialog both default to these folders (falling back to the equivalent source-tree paths in a dev checkout), so a fresh install ships ready-to-run examples instead of requiring an operator to find them in a source checkout. `Workspaces/` is explicitly import-and-edit examples, not live device config - the gantry backend loads named workspaces from its own copy on the bench Pi. Wired into both build paths (`make dist` and the CI Windows build, which invokes the packaging steps directly rather than via `make dist`).

### Changed

- `gantry` (2026-08-05): added `24_well_5ml` labware (24-well rack sized for 5ml vials, `well_depth_mm=60`) and switched the `3_24-well_wWash` workspace's three 24-well plates from `24_well_15ml` to it. `washing_station` well depth 45 -> 40mm and footprint `height_mm` 85.48 -> 93.58mm.

### Fixed

- `client` (2026-08-05): `RxnBenchClient.set_log_output()` no longer silently overwrites an existing results file with the same name - if the resolved path already exists, `_1`, `_2`, ... is appended to the filename stem until an unused one is found. A re-run of a script with the same log filename (e.g. `ph_sample.csv`) now produces `ph_sample_1.csv` instead of clobbering the previous run's data.

## [v0.1.4] - 2026-08-04

Dosing pump device added and verified against real hardware (UART smoke test + a fixed concurrency bug), gantry labware/rotation fixes for the new 24-well 15mL rack, and client-side logging resilience.

### Changed

- `client` (2026-07-24): reconditioned `PHProbe.read_stable` defaults so the stability gates are statistically sound for this probe's noise. `window` 5 -> 10 and `max_range` 0.02 -> 0.03. The OLS slope's standard error is `sigma/sqrt(sum (t-tbar)^2)`, ~0.0022 pH/s at window=5 vs ~0.0008 at window=10; with the probe's measured per-reading noise `sigma ~= 0.007 pH` (from `results/ph_traces`), window=5 put the slope SE *above* `max_drift=0.002`, so a settled probe failed the drift gate ~35% of windows on noise alone (erratic settle times / spurious timeouts). Peak-to-peak grows with window size (`E[ptp] ~= 3.1*sigma ~= 0.021` at window=10), so `max_range` was loosened to 0.03 to avoid rejecting settled windows. `_StabilityMonitor` math (OLS slope / ptp / window mean) was reviewed and is correct; only the defaults changed. `scripts/tune_endpoint.py` `EndpointConfig` updated to match, and its trace loader now tolerates truncated CSV rows (`float(None)` -> `TypeError` was uncaught). Note: re-tuning against the current traces still fails the accuracy bar because those samples barely settle - physical settling (submersion/mixing, longer `TRACE_SECONDS`) is the limiter, not the detector.
- `gantry` (2026-07-23): raised the `ph_probe` toolhead `z_engage` from 40 to 65 mm. Because `_effective_engage_depth` blends `z_engage` with each well's `well_depth_mm`, the switch of the 6-well holder from 50 mL (`well_depth 100`) to 25 mL tubes (`well_depth 77`) had silently reduced the probe's descent from ~70 mm to ~58.5 mm, leaving the junction insufficiently submerged and skewing readings. 65 restores ~71 mm in the 25 mL tubes and lets the `well_depth − engage_bottom_margin` cap govern the shallower calibration/wash wells (probe now seats ~2 mm above their bottoms). Deploy: sync `toolheads/` to the Pi + restart `rxn-bench-gantry`.
- `client` (2026-07-15): `PHProbe.read_stable` automatic endpoint detection instead of the "N consecutive readings within a tolerance band" check. Readings stream into a rolling window (`window`, default 5) and, once the window is full and at least `min_settle` s (default 5) have elapsed
- `gantry` (2026-07-15): tool engagement depth is now derived from the labware, not only the toolhead config. `GantryController._effective_engage_depth` blends the toolhead's configured `z_engage` with the docked well's own measured `well_depth_mm` (the mean of the two) and caps the result a fixed gap above the well bottom (`MachineConfig.engage_bottom_margin_mm`, new, default 2 mm). This *replaces* the previous hard rejection when `z_engage` exceeded a well's depth: a toolhead configured deeper than a shallower plate's wells - e.g. the bench `ph_probe`'s `z_engage=40` on a 36 mm-deep 96-well plate, which was being refused outright - now engages, capped, instead of blocking the move. The controller tracks the docked well `_current_well_label`, set by `move_to_well`.

### Added

- `dosing_pump` (2026-07-29): new device - Atlas Scientific **EZO-PMP** embedded peristaltic dosing pump as `rxn-bench-dosing-pump` on port 50054. Exposes all four datasheet dispensing modes (fixed volume `D,[ml]`, dose over time `D,[ml],[min]`, constant flow rate `DC,[ml/min],[min|*]`, continuous `D,*`) plus pause/stop/invert, single-point calibration, and net/absolute total-volume counters. Adds `devices/dosing_pump/{backend,frontend}`, the `DosingPump` SiLA feature, a `rxn_bench_client.DosingPump` instrument (with `dispense_and_wait()` for scripts that must block until liquid is actually delivered), and a Qt widget.

  The frontend plugin follows the **pH widget as its baseline**: a `ui/dosing_pump_widget.ui` loaded via `QUiLoader` with `findChild` lookups, one 44pt hero readout for dispensed volume, and a custom-painted `VolumeGraph` history trace injected into a placeholder. The graph auto-scales its Y axis (a dose can be 0.5 ml or 500 ml, unlike pH's fixed 0-14) and greys the trace while the pump is idle. A **mode combo** (Volume / Dose over time / Constant rate / Continuous) enables only the inputs each mode uses and relabels the action button, mirroring how the pH widget's calibration-point combo gates its value spin - this replaced a first pass that stacked six `QGroupBox`es with no `.ui` file and no graph. Note that setting *any* Qt stylesheet replaces the default disabled palette, so the mode-gated inputs, labels, and the Stop button each need explicit `:disabled` rules or they look active while disabled.

  A **new device rather than a reuse**: the pump is an actuator, and `DosingPumpProtocol` has no overlap with `PHSensorProtocol` (read/calibrate/slope), `CameraProtocol` (`capture()`), or the gantry's motion protocol. The Atlas EZO *UART wire protocol* is shared with `rxn_bench_ph` and is deliberately re-implemented rather than imported, per the per-device self-containment rule (`docs/ai/CURRENT_STATE.md` §8) - the shape is copied (transport-agnostic `EZOPumpCommandSet` + one transport class), not the code. Only UART is implemented; the command set stays transport-agnostic so the pump's I2C mode can be added later as a transport class.

  Two EZO-PMP protocol quirks the pH circuit doesn't have, both handled explicitly: `*DONE,<volume>` is *both* the only reply to `X` (stop) *and* an unsolicited interrupt whenever a dispense finishes on its own, so the driver accepts it as a reply only when the in-flight command expects one (`done_terminates`) and otherwise records it in `last_completed_volume` and skips it - without that, a dose completing during an unrelated query (e.g. `TV,?`) would silently return the dispensed volume as the total. And `*MINVOL` (below the 0.5 ml minimum) / `*TOOFAST` (above the calibrated max) are command rejections distinct from plain `*ER`, surfaced as `ValueError` naming the cause. The pump's two *toggle* commands (`P`, `Invert`) are wrapped as idempotent setters that read current state first, so scripts assert a state instead of tracking parity.

  `MockEZOPumpUart` emulates the protocol and *simulates dispensing against an injectable clock*, so the real driver stack runs without hardware and a dose actually progresses and completes over its requested duration (the mock server is genuinely drivable, not a constant-returning stub). 77 backend tests. Verified end-to-end against a live mock server over real gRPC - progressive dispensing, `Stop`'s float return, unobservable-property reads, error propagation - plus the real Qt widget constructed and driven headlessly.

  Driver-level circuit housekeeping (`find`, `set_led`/`get_led`, `sleep`/`wake`, `set_protocol_lock`/`get_protocol_lock`) is present on `EZOPumpCommandSet`/`AtlasDosingPump` but deliberately **not** exposed over SiLA, matching how `rxn_bench_ph` keeps the same group driver-level only. `sleep()` needs a paired `wake()`: the byte that wakes a sleeping EZO is consumed doing so and is *not* executed - the circuit answers `*WA` and the command is silently lost - so `wake()` absorbs that throwaway exchange (`MockEZOPumpUart` reproduces the swallow, so it's tested rather than assumed). Note `sleep()` only powers down the control system, not the 12-24 V motor supply. Not implemented on purpose: `Baud`/`Factory`/`Name`/I2C-switch (can strand the connection mid-run), `O` (changes the output string format `R` parsing depends on), and `Dstart` (runs the pump on power-up without a client).

  **Not yet run against physical hardware.** Two things to resolve first: the EZO-pH already owns the Pi's primary UART (`/dev/serial0`), so the pump needs its own port (`dtoverlay=uartN` or a USB-serial adapter, via `RXN_BENCH_PUMP_SERIAL_PORT`), and the pump requires **two** supplies - 3.3-5.5 V logic *and* 12-24 V motor; logic-only will look alive over UART but never turn the motor. See the new gaps in `CURRENT_STATE.md` §6.
- `dosing_pump` (2026-08-04): made the device reusable by a second pump model rather than welded to the EZO-PMP, per the minimally-viable-interface goal. Three changes, no wire-format break:
  - **`DosingPumpProtocol` trimmed to a 12-method core** every dosing pump can satisfy. The vendor-specific parts moved into opt-in `runtime_checkable` capability protocols: `SupportsCalibration`, `SupportsDirectionInvert` (a *persistent* flip is an EZO feature; most pumps just take a signed volume), and `SupportsDiagnostics` (`pump_voltage` is the EZO's `PV,?`; a syringe pump has no equivalent). The feature probes them with `isinstance` and rejects only those commands, naming what's missing, instead of throwing `AttributeError`. `GetCalibrationStatus`'s docs no longer present the EZO's 0/1/2/3 as universal - 0 is uncalibrated, non-zero is pump-defined.
  - **No model-specific numbers left in the widget.** It dropped a hardcoded `105.0` and the `.ui`'s 0.5 ml / 105 ml-min limits; the Rate ceiling comes from the server's `MaxFlowRate` at runtime and per-pump minimums are enforced by the device and surfaced as errors. Hardcoding one pump's limits into UI that's matched by *feature identifier* would have broken every other pump that reuses it.
  - **`server.py` gained a `_DRIVERS` registry** keyed by `RXN_BENCH_PUMP_DRIVER` (default `atlas_ezo_pmp`), so adding a model is one builder entry, not an edit to the hardcoded Atlas path.

  Net effect: a second pump = one driver class + one registry line. No new frontend code, proto, connection layer, or client class, because `rxn_bench_ui` matches plugins on the advertised SiLA feature identifier (`FEATURE_FRAGMENTS`), not on hardware. Covered by tests that assert a core-only fake pump satisfies `DosingPumpProtocol`, drives every dispensing command through the feature, and fails exactly the six unsupported-capability calls (96 backend tests, up from 88).
- `dosing_pump` (2026-08-04): first real-hardware verification. The bench Pi 5's `dtoverlay=uart2` (already present in `config.txt`) brings up UART2 on GPIO4/5 (TXD2/RXD2) as `/dev/ttyAMA2` - confirmed by pin function (`pinctrl get 4,5` -> `a2`) and by talking to the physical EZO-PMP over it: `?I` returned `PMP,1.06`, `?STATUS` and `PV,?` both responded, and the motor supply read 11.99 V. `install_service.sh`'s device registry gained a per-device `env_vars` field (`Environment=` lines in the generated unit) so the `pump` service now gets `RXN_BENCH_PUMP_SERIAL_PORT=/dev/ttyAMA2` automatically instead of defaulting onto the pH probe's `/dev/serial0`. Only a UART smoke test (`?I`/`?STATUS`/`PV,?`) was run against real hardware - dispensing, calibration, and the `*DONE` mid-query interrupt path are still unverified on the physical pump; see `CURRENT_STATE.md` §6.
- `gen_proto.py` (2026-07-29): added an `Integer` SiLA primitive wrapper (`message Integer { int64 value = 1; }`, plus `int` in `_SILA_TYPE`), needed by the dosing pump's `GetCalibrationStatus`. Second generic generator addition after the camera's `Binary`; verified to decode correctly against a live server. Declaring it `Real` would have broken decoding outright - the CDK sends a varint for a Python `int`, not a fixed64.
- `ci.yml` (2026-07-29): added the missing `make test-camera` step alongside the new `make test-pump`. The camera backend suite existed and was runnable locally but was never actually run in CI, despite `CURRENT_STATE.md` claiming coverage.
- `instrument.py` added a `Gantry.shake()` method which oscillates the gantry N number of times over `amplitude`, this is useful for flinging off excess liquid or material on the toolheads
- `client` (2026-07-15): two scripts for empirically tuning the pH endpoint detector against real hardware. `scripts/record_ph_traces.py` parks the probe in each well and logs the full pH-vs-time trace (instead of stopping early). `scripts/tune_endpoint.py` replays the shipping `_StabilityMonitor` over those traces across a grid of thresholds and reports, per config, median settle time, endpoint error vs. the trace's equilibrium (tail average), and premature-stop / timeout rates - so `read_stable`'s defaults can be chosen from this probe's data rather than borrowed. It reuses the production detector (not a copy) and runs offline against built-in synthetic traces when no recorded ones are given.

### Fixed

- `dosing_pump` (2026-08-04): fixed a real race condition found while verifying the pump against physical hardware - the SiLA feature polls two observable properties (`VolumeDispensed`, `Dispensing`) concurrently at 1Hz, each dispatched to its own OS thread via `asyncio.to_thread`, and any in-flight `Dispense`/`Stop` call from a script joins them; all shared one `serial.Serial` port with nothing serializing access. Two threads' writes/reads interleaved on the wire, producing garbled replies on the real EZO-PMP (`ValueError: could not convert string to float: 'O'`, `'D,100,'`, `'OK?-.0,0*'`) - never seen against the mock because `rxn_bench_ph` (the only prior EZO device) exposes just one observable stream, so this is the first concurrent-access path in the codebase. `EZOPumpCommandSet` gained a `threading.Lock` and a `_transact(cmd)` helper that performs each command's send+read as one atomic exchange; every command method now goes through it instead of calling `_send_command`/`_read_response` separately. Verified fixed against the real pump: 30 concurrent calls across two threads (15× `read_volume_dispensed`, 15× `get_dispense_status`), zero errors. All 96 backend tests still pass.
- `gantry` (2026-08-04): fixed the new `24_well_15ml` labware's well grid not being centered on its own plate footprint. `a1_offset_x`/`a1_offset_y` had been set from a "4mm wall clearance + well radius" formula rather than measured, which didn't reconcile with the confirmed plate footprint (127.90 × 85.50 mm) and caliper-measured spacing (21.75/21.53 mm) - the last column/row's wells landed asymmetrically (up to 1.35mm past the right edge). Recalculated to `a1_offset_x=9.58`, `a1_offset_y=10.46`, centering the grid on the footprint per the CAD drawing's own origin.
- `gantry` (2026-08-04): added `Orientation.ROTATED_270` (a 90° **clockwise** rotation, `(dx,dy) -> (dy,-dx)`) alongside the existing `ROTATED_90` (counter-clockwise). The three `24_well_15ml` plates in the `3_24-well_wWash` workspace need the opposite rotation direction from what `ROTATED_90` provides - A1 was landing on the wrong side of the plate. Implemented identically in `workspace_manager.py` (backend) and `workspace_loader.py` (frontend canvas, via a shared `_apply_orientation` helper) so the deck rendering and the real motion math never diverge. 3 new backend tests mirror the existing `ROTATED_90` cases.
- `client` (2026-08-04): `RxnBenchClient.log()` now catches `OSError` around the actual file write (header/row/flush) and skips that row with a printed warning instead of raising - a logging hiccup (e.g. a results folder on a network share that drops) no longer takes down an otherwise-healthy experiment run. The "forgot to call `set_log_output()` first" `RuntimeError` still raises, since that's a real script bug. **Known gap, not fixed:** none of the underlying SiLA/gRPC calls (`bench.ph.read()`, `bench.gantry.move_to_well()`, etc.) have a deadline - `sila2`'s `SilaClient` builds its channel with plain `grpc.insecure_channel` and never passes a per-call `timeout`, so a genuinely dead connection (e.g. the operator machine's ethernet unplugged) still hangs a script indefinitely rather than erroring. See `CURRENT_STATE.md` §6 for the fix options (client-only keepalive bounds it to ~5 min; going faster requires touching all four device backends' server config).

## [v0.1.2]

An important milestone was reached, the entire system, `gantry`,`ph_sensor`,`client`,`frontend` was able to perform a script `calibrate_ph.py`
which automatically calibrates the pH probe. This is important and proves the viability/usability of the system for many more experiments to come.

### Current Issues

- Gantry positioning: gantry is accurate enough to reliability move to and engage/disengage in a 24 well-plate, however struggles with smaller 96-well
plates. We'll need to confirm and verify all measure inside the `labware/`, `workspace/`, and `toolhead/` `.yaml` config files to see if there is an
improvement.

### Added

- `ph_sensor`: Ability to set tempeature compoensation was added into the interface, SiLA feature, client `instrument.py`, and EZO drivers. 
- `docs/build_all_docs.sh` script which builds the sphinx / generates UML for the entire repo
- `clean-repo/SKILL.md`: agent skill which cleans the repo of redundant code, cleans up excessive inline comments, and simplifies project structure,
to avoid overly nested folders etc.

### Changed

- `instrument.py:288` pH probe `read_stable` now keeps a rolling window of the last samples readings and only returns once the whole window spans ≤ tolerance (max - min), instead of just the latest pair
- `server.py:43`: the default speed of `moonraker_client()` was increased from `3000` to `4000`: `moonraker_client(host, DEFAULT_SPEED=4000)`

### Fixed

- Doc generation
- `ph_sensor`: the ph sensor was having problems calibrating, a written script `calibrate_ph.py` was created, the fix was to decrease the tolerance
and increase the interval to gather a more stable reading, as well as ensuring the probe was fully submerged into the sample.
- `client.py`: default log location was changed to the `root/results/` directory of the running frontend application unless specified.
- frontend: the packaged app can now actually run experiment scripts. The PyInstaller spec never bundled `rxn_bench_client` (nor its `sila2` / `grpc_tools` dependencies) - scripts are loaded only dynamically via `runpy` when the Experiment Runner runs one, so PyInstaller's static analysis never saw them - and the frozen app threw `ModuleNotFoundError: No module named 'rxn_bench_client'` on the first script run. The spec now `collect_all`s `rxn_bench_client`, `sila2`, and `grpc_tools` (the last needed because sila2 compiles FDL to gRPC stubs at runtime, and its Cython `_protoc_compiler` imports `grpc_version` invisibly to static analysis), matching how device-plugin deps (`yaml`, `connections.base`) are already handled. Verified by running a script through the real frozen exe. (2026-07-14)

## [0.1.1] - 2026-07-13

### Added

- frontend: `windows-latest` GitHub Actions workflow that builds the Windows desktop installer, uploads it as an artifact, and attaches it to version-tag GitHub Releases (so the `.exe` can be produced from a Linux dev machine).
- gantry: the X-gantry crossbar is now drawn in the workspace X/Z and Y/Z side views (under "show more details").
- gantry: opt-in crossbar collision check - refuses a well move or tool engagement that would drive the crossbar into a taller plate sharing the carriage's Y-row. Needs crossbar measurements in `machine.yaml` to activate.
- gantry: configurable `deck_height_mm` workspace field for the shared deck/workplate thickness, separate from each plate's own mount height and footprint. Defaults to 0, so existing workspaces are unchanged.

### Changed

- gantry: bumped the Gantry SiLA feature from v0 to v1 (`edu.iastate.ames/rxnbench/Gantry/v1`), matching pH and Camera. Frontend and backend must be deployed together.
- gantry: moving between wells of the same plate now travels at that plate's own clearance height instead of the full-deck safe height, cutting raise/lower time on multi-well scans.

### Fixed

- gantry: corrected `test_controller.py` cases that hardcoded plate dimensions instead of deriving them from the labware YAML.

## [0.1.0] - 2026-07-13

### Added

- camera: new `rxn_bench_camera` SiLA device (port 50053) that streams the latest webcam frame from a Crowsnest stream, with an adjustable capture interval and image archiving. Adds a generic SiLA `Binary` wire type and `snapshot()` / `save_snapshot()` / `set_capture_interval()` on the client.
- gantry: multi-toolhead support - several heads can be mounted at once, each confirmed once and then switched between in software; moves refuse an unmounted or uncalibrated head, and both UI slots drive their own head.
- gantry: backend enforces the experiment lock on the wire - `AcquireExperimentLock` returns a token and motion/toolhead/workspace commands take an optional `Token`; the client attaches it automatically.
- gantry: `ForceReleaseExperimentLock` - tokenless recovery for a lock stranded by a killed script, wired into the UI banner and the client.
- gantry: `GetLabware` command serves all plate-geometry YAML as the single source of truth; deck canvases and the client fetch it instead of hardcoding grids.
- gantry: non-contact Z-reference calibration - the homing dialog and toolhead wizard can hover the tip at a known reference-plate height instead of touching a surface.
- gantry: new X/Z and Y/Z workspace side views alongside the top-down view, on both the Live and Configuration tabs, showing plate heights, the deck floor, safe-travel height, and per-well engagement depth.
- ph: UART/serial driver for the Atlas EZO-pH circuit (the bench probe is wired to the Pi's UART, not I2C), selected via `RXN_BENCH_PH_TRANSPORT`, sharing one EZO command set with the I2C driver plus a serial mock.
- client: `at_well()` gains an `override_unvalidated` passthrough so scripts can use a toolhead whose geometry is still placeholder.
- frontend: PyInstaller packaging groundwork - `make dist` builds a onedir app and stages each device plugin beside the executable; plugin discovery resolves `devices/` from the executable when frozen.
- frontend: closed the four gaps in the generic FDL-driven device widget - typed protobuf messages built from the FDL, typed command inputs with validation, and observable-command support - so it drives unknown SiLA2 devices without compiled stubs.
- backend: `install.sh` (shared uv workspace for dev) and `scripts/install_service.sh` (per-package venv plus the pH `rpi` extra) so each service deploys as its own systemd unit.
- docs: `new-device` dev-agent skill for scaffolding a device, requiring reuse of existing device interfaces before creating new ones.
- docs: top-level `devices/<name>/README.md` overviews for gantry, ph_sensor, and device_template.
- testing: first test suites for the pH backend, the client (37 tests), and the frontend (15 tests), plus the gantry suite extended to 133 tests.
- repo: GitHub Actions CI running both backend suites, the frontend suite, and both drift checks on push/PR.

### Changed

- repo: renamed the top-level `software/` folder to `rxnbench/` (`rxnbench/backend`, `rxnbench/frontend`) - path references updated and generated artifacts regenerated, no architecture change.
- repo: reorganized to a device-first layout - each device is a self-contained `devices/<name>/{backend,frontend}` folder.
- gantry: safe clearance-travel height is now derived from the loaded labware geometry (new `plate_height_mm`) instead of a flat 50 mm guess.
- ph: frontend connection uses generated protobuf stubs instead of hand-rolled varint helpers (also updated in `device_template`).
- frontend: gantry workspace loader now goes through `GantryConnection` instead of opening raw gRPC channels - closing the last plugin->core-internals boundary violation.
- backend: `gen_proto.py` generalized to a per-device manifest covering gantry, pH, and the template; adding a device's stubs is one entry.
- backend: offline-bundle default target Python is now 3.13 (the reference Pi's OS ships it); override with `PYTHON_VERSION`.
- docs: refreshed `CURRENT_STATE.md` - closed gaps removed, new stable decisions recorded.

### Fixed

- frontend: Experiment Runner now runs the selected script in packaged builds instead of relaunching the app.
- deployment: SiLA server discovery on the gatewayless bench network - servers now advertise the Pi's real IP over mDNS and a boot-time multicast route lets announcements reach the wire; `install_offline.sh` auto-detects and pins the host IP.
- gantry: `move_to_well` docks at the well's actual opening and rejects a move whose engage depth exceeds the well depth, instead of overshooting.
- gantry: lock-gated commands (`LoadWorkspaceYaml`, `Jog`, `MoveTo`, …) no longer fail with "Missing field Token" - the token arg is now declared for each, with a regression test cross-checking spec args against the proto.
- gantry: toolhead calibration wizard no longer rejects auto-moves against a plate shallower than the toolhead's configured engage depth.
- gantry: one broken labware file no longer breaks `GetLabware` for every plate - bad definitions are skipped with a warning and a clear error names the file.
- gantry: `GetWorkspaceYaml` and its subscription read from the controller's workspace manager, so workspaces loaded by name or restored at boot are visible to the stream and client.
- gantry: `MoonrakerClient` HTTP calls carry timeouts, so a wedged Moonraker no longer hangs a request while holding the hardware lock.
- gantry: fixed `motion_platform.proto` drift - the generator footer was missing the experiment-lock/pause/resume/stop RPCs.
- ph: fixed the real-hardware I2C path - new `SMBusI2C` adapter (passing `SMBus(1)` directly would have crashed) plus a mock I2C emulator for tests.
- frontend: packaged builds now bundle device-plugin dependencies (`collect_submodules`, `yaml`); `make dist-check` constructs every device widget in a frozen build to catch missing imports.
- frontend: connection layer now logs stream/command failures, closes channels on disconnect, and surfaces errors in the UI.
- backend: `make start-gantry` / `-ph` / `-camera` run fully offline from an extracted bundle; also fixed `start-ph` never installing the `rpi` extra (smbus2).
- backend: `install_offline.sh` persists the vendored `uv` on `PATH` so `make start-<device>` works right after install.
- backend: `build_offline_bundle.sh` - fixed requirements-file parsing (single-line exports), aarch64 wheel downloads (`manylinux2014_aarch64` tag), and the tar step pulling in its own output.
- backend: offline `install_service.sh` now bundles its build backend (`hatchling` / `editables`) so editable installs succeed with no network.
- docs: fixed `device_template/README.md`'s onboarding checklist (stale `sila_client.py` / `_FEATURE_REGISTRY` references and old spec paths).

### Removed

- gantry: dead-code sweep - unused sensor registry, an unconsumed signal, phantom widget fields, speculative generic SiLA fragments, and a phantom 384-well plate entry.

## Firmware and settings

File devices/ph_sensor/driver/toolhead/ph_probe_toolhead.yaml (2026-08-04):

name: ph_probe
display_name: Atlas Scientific pH Probe
sensor_type: ph

geometry:
  footprint_x: 44       # mm
  footprint_y: 25       # mm
  offset_x: 0           # mm, kept at 0 - do not hand-guess this; measure via the calibration
  offset_y: 0           # wizard instead, which folds the *entire* correction into tip_x/tip_y
                        # below and saves it locally (~/.rxn_bench/toolhead_calibration.json),
                        # not into this checked-in file.
  tip_x: 0              # mm
  tip_y: 0              # mm
  tip_offset_z: 0 #110     # mm, below carriage mount
  z_engage: 65          # mm, requested descent into a well. Actual descent is
                        # min((z_engage + well_depth)/2, well_depth - engage_bottom_margin),
                        # so this is blended with each well's depth and capped 2mm above
                        # its bottom. 65 keeps the probe junction submerged in the 25mL
                        # tubes (~71mm) and near the bottom of the shallower cal/wash wells.
  geometry_validated: false  # tip_x/tip_y are placeholders, not yet measured

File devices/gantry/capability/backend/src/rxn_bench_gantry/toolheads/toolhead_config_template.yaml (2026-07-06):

# toolhead_config_template.yaml
# Dfaults for all toolhead configs.
# Copy this into your toolhead folder and fill in the values.
#

name: toolhead_name          # internal name, matches the folder
display_name: Toolhead Name  # shown in UIs and SiLA
sensor_type: null            # optional metadata tag, e.g. 'ph'.

geometry:
  footprint_x: 0.0           # mm
  footprint_y: 0.0           # mm
  offset_x: 0.0              # mm
  offset_y: 0.0              # mm
  tip_x: 0.0                 # mm
  tip_y: 0.0                 # mm
  tip_offset_z: 0.0          # mm, below carriage mount
  z_engage: 0.0              # mm
  geometry_validated: true    # set false until tip_x/tip_y/etc. are physically measured

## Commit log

2026-06-06 work on modeling
    [Mounting Plate Test Fit.stl, Mounting Plate.stl, Test well plate fit.3mf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]
2026-06-19 Add backend service structure, frontend UI, and interfaces
    Includes SiLA feature implementations, IO interfaces for motion platform
    and pH sensor, frontend Qt widgets, main window, labware definitions,
    and architecture documentation.
    [Mounting Plate Test Fit.stl, Mounting Plate w magnets.stl, Mounting Plate.stl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]
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2026-06-19 Update current_state.md: communication layer review, remaining risks, scaling assessment
    Marks proto codec migration complete (weaknesses 4 and 5 resolved),
    updates module map for app.py split, adds Remaining Risks and Future
    Scaling Assessment sections post-migration.
2026-06-25 Refactor backend to Gantry/WorkspaceManager architecture, add tests and proto stubs
    Replaces MotionPlatform/MotionPlatformController with Gantry feature and
    GantryController. Adds workspace-aware well navigation, plate geometry
    library, machine config externalisation, and mock pH sensor.
    Key changes:
    - io/motion_platform/ → io/gantry/ (rename + slim orchestrator pattern)
    - features/motion_platform.py → features/gantry.py (workspace commands added)
    - labware/well_plate.py → io/labware/plate_geometry.py (PlateGeometry dataclass)
    - io/workspace/ added (WorkspaceConfig + WorkspaceManager)
    - machine_config.py: axis limits loaded from ~/.chem_bench/machine.yaml
    - io/ph/mock_ph_sensor.py: Mo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
2026-06-30 Restructure to uv workspace, split frontend, strip dead code and clean comments
    Backend:
    - Replace monolithic src/chem_bench/ with uv workspace packages: gantry,
    ph_sensor, client, device_template. Each runs as its own SiLA service.
    - Remove requires_manual_z and requires_manual_homing from ToolheadGeometry;
    manual homing is always required so the flags were dead weight.
    - Fix workspace_1.yaml: name was copy-pasted 'workspace_name', orientation
    was invalid 'rotated_0' (valid values: standard, rotated_90).
    - Regenerate motion_platform.proto and _pb2.py to match updated dataclasses.
    Frontend:
    - Split monolithic app.py/main_window.py/widgets/ into core/, devices/, and
    module-per-concer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
    [Belt Clamp.stl, Mount Pin.stl, Mounting Plate w magnets.stl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]
2026-06-30 Fix toolhead YAML indent corruption and workspace canvas orientation
    ph_probe_toolhead.yaml: comment cleanup agent de-indented tip_y and
    tip_offset_z out of the geometry block, making the YAML unparseable.
    ToolheadConfig.from_yaml() silently swallowed the ParserError so
    ListToolheads returned empty. Fixed indentation.
    workspace_loader.py WorkspaceCanvas: orientation field was read from
    the YAML but never applied when drawing. Added _well_gxy() helper that
    applies the same -plate_dy / plate_dx rotation as the backend
    _apply_orientation(), updated plate rectangle corners and well positions
    for rotated_90, and updated the bounding box calculation so rotated
    plates are included in the auto-scal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
    [ph_probe_toolhead.yaml]
2026-06-30 Add Live tab to gantry widget with action status and position overlay
    Right panel now has two tabs:
    - Live: shows current action (Standby / Moving / Manual Homing / Activating
    Tool / Error), last well navigated to, and a workspace canvas with a
    yellow crosshair at the live gantry XY position and a green highlight
    on the active well.
    - Configuration: the existing workspace loader (unchanged).
    WorkspaceCanvas gains set_active_well() and set_current_position() for
    the live overlay. WorkspaceLoaderWidget emits workspace_changed(dict)
    whenever a valid workspace is parsed so the Live canvas stays in sync.
    GantryWidget tracks a _pending_action string updated on button clicks
    (toolhead activ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
2026-06-30 Add ph_scan.py experiment script and fix ChemBenchClient field names
    ph_scan.py drives a full A1–A6 well scan: loads workspace YAML inline,
    sets ph_probe toolhead, then loops move → engage → settle → read pH →
    disengage, printing per-well results and a summary table. Parking errors
    (e.g. homing not calibrated in mock sessions) are caught as warnings.
    Fix ChemBenchClient.list_workspaces and list_toolheads to use Response0
    (the actual sila2 client field name) instead of the non-existent Workspaces
    / Toolheads attributes. Export ChemBenchClient from __init__.py.
2026-06-30 Replace sila2 client with compiled proto stubs in ChemBenchClient
    The sila2.client.SilaClient library ignores proto field names and uses
    positional placeholders (Response0, Response1, ...) regardless of what
    the schema declares. Replacing it with direct gRPC + compiled protos
    gives us the real names: resp.Workspaces.value, resp.Toolheads.value,
    resp.Limits.value, resp.ToolheadInfo.z_engage.value, etc.
    Changes:
    - Copy motion_platform_pb2.py into client/src/chem_bench_client/proto/
    - Rewrite client.py to use compiled proto messages and raw grpc channels
    (channel.unary_unary / channel.unary_stream)
    - Swap pyproject.toml dependency from sila2 to grpcio + protobuf
    - pH reading uses a small han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
2026-06-30 Add CurrentWell and CurrentAction server-side observable properties
    The gantry feature now tracks what it is doing as observable state so any
    client — the UI, a script, a future remote dashboard — gets live updates
    without needing to infer them from button clicks or state strings.
    Server (feature.py):
    - _current_well / _current_action instance variables
    - current_well ObservableProperty: updated after each move_to_well call
    - current_action ObservableProperty: set to e.g. "Moving to plate1/A3",
    "Engaging tool", "Disengaging tool", "Parking", "Manual Homing", then
    reset to "Standby" in a finally block so crashes don't leave stale text
    - move_to, move_to_well, engage_tool, disengage_t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
    [feature.py]
2026-06-30 Add session logging, View menu, CSV Viewer, Experiment Notes, and UI fixes
    - Add SessionLog class (JSONL per server session, 30-day rotation, per-device logs/ dir)
    - Wire logging into gantry feature via _run() helper (single log path for all hw calls)
    - Wire logging into ph_sensor (calibration events) and device_template
    - Each device logs to its own logs/ subdirectory with a prefixed filename
    - Add View menu (File → Settings → View) with toggleable core panels
    - Add CSV Viewer panel: live-updating table view of any CSV file
    - Add Experiment Notes panel: text editor with save/load and dirty-state tracking
    - Multiple workspace tabs with + button, custom × close button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
    [feature.py, session_log.py]
2026-07-02 Rename chem-bench to rxn-bench, split backend/frontend, reorganize to device-first layout
    Consolidates a large uncommitted working-tree state into one commit:
    - Rename all packages/imports from chem_bench_* to rxn_bench_* (gantry, ph_sensor,
    client, device_template, frontend UI), matching the "Rxn Bench" project name.
    - Split the backend into independently deployable per-device SiLA2 server
    packages (rxn-bench-gantry, rxn-bench-ph) under a uv workspace, plus a
    reference device_template package and a script client package.
    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
    [2026-06-03 162541_test1.csv, 2026-06-03 163524_test2.csv, 2026-06-03 163604_test3.csv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]
2026-07-02 Fix motion_platform.proto drift and add real ph_sensor test coverage
    - gantry: gen_proto.py's hand-maintained _FOOTER template was missing the
    ExperimentLock/Pause/Resume/Stop/GetExperimentState/ExperimentActive RPCs
    that the checked-in proto (and feature.py) already had, so `make check-proto`
    was failing. Updated the template and regenerated; the compiled
    motion_platform_pb2.py is byte-identical, so this is a template fix with
    no functional change.
    - ph: add devices/ph_sensor/backend/tests/ (30 tests) covering
    AtlasScientificEZO's I2C wire-protocol parsing via a fake I2C bus double,
    AtlasPHSensor's calibration dispatch and status parsing, MockPHSensor, and
    the PHSensor SiLA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
2026-07-02 Close all four gaps in the generic FDL-driven device widget
    The generic device widget (core/generic_device.py) is the automatic fallback
    for any SiLA2 device that doesn't match a known frontend plugin. It already
    worked, but its wire encoding/decoding was entirely heuristic (_collect_values
    guessed value types from raw protobuf bytes; _encode_param hand-built each
    basic type's wire format). Four real gaps followed from that:
    1. Dynamic FDL->protobuf construction (new core/fdl_types.py). Builds real,
    typed protobuf messages at parse time from the FDL itself, using
    google.protobuf.descriptor_pb2/descriptor_pool/message_factory - no
    compiled stubs needed, since the whole point is hand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
2026-07-02 docs: correct CURRENT_STATE.md against verified codebase findings
    Phase 1 investigation found several claims needed correction: the gantry
    backend already has a 56-test suite (just thin on MotionEngine, the
    manual-homing state machine, and toolhead-aware bounds), the experiment
    lock doesn't actually gate motion RPCs (executes rather than rejects),
    motion_platform proto stubs violate the device-first layout, and
    generated_connection.py has no drift check at all. Also documents the
    session_log.py duplication as an intentional per-device tradeoff and
    fixes the "allround" typo.
2026-07-02 test(gantry): full backend test suite rewrite mirroring pH structure
    The existing suite (56 tests) had zero direct coverage of MotionEngine's
    raise-XY-lower sequencing and HomingManager's manual-homing state machine,
    and no toolhead-aware bounds coverage in GantryController. Replaces the
    mislabeled test_feature_discovery.py (a stale copy of frontend matching
    logic that no longer corresponds to any real frontend code) with real
    feature.py tests, including a characterization test pinning the known
    experiment-lock gap. Adds a shared FakeMotionClient test double and makes
    homing_state file isolation automatic via conftest, matching the existing
    workspace_manager isolation. 108 tests, ~0.7s.
    Co-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
2026-07-02 fix(gantry): gate homing/calibration dialog jog controls on experiment lock
    Investigation for this pass found the main widget already has an
    experiment-running banner, working Pause/Resume/Stop buttons, and
    _set_controls_locked() disabling toolhead-management buttons (including
    the ones that launch the Homing and Toolhead Calibration dialogs) - all
    pre-existing, not part of this change. CURRENT_STATE.md's gap description
    was stale on this point.
    The one real gap: neither dialog listened for experiment_active_changed,
    so if one was already open when a script acquired the lock, its jog and
    confirm-position buttons stayed live. Both dialogs now show a lock banner
    and disable their jog/confirm/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
2026-07-02 build(frontend): add generated_connection.py drift check
    gen_connections.py existed as a generator but nothing wrapped it in a
    Makefile target, let alone diffed its output against a regenerated copy -
    unlike the gantry proto path, which already had make check-proto. Adds
    software/frontend/Makefile with gen-connections (regenerate in place) and
    check-connections (regenerate to a temp file, diff, fail loudly on drift).
    Both loop over devices/*/frontend/connection_spec.yaml generically, so
    new devices are covered without editing the Makefile. Verified check-
    connections both passes cleanly against the current tree and fails with
    a clear message when a file is deliberately made stale.
    Co-Author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
2026-07-06 build(backend): generalize gen_proto.py to a per-device manifest
    One generator (software/backend/scripts/gen_proto.py) with a _DEVICES manifest
    replaces the gantry-only script; make gen-proto / make check-proto now loop
    over gantry, ph_sensor, and device_template. Adding a device's frontend stubs
    is one manifest entry. Generated protos pick up the new gantry commands and
    fields (token parameters, GetLabware, ToolheadInfo.mounted_toolheads).
2026-07-06 refactor(frontend): connection-core cleanup and observability
    - Remove the never-consumed feature_state_changed signal end-to-end: the
    Qt signal in connections/base.py, the feature_name spec field, and the
    gen_connections.py generator branch that emitted it.
    - Log stream failures (first failure per outage at WARNING, retry churn at
    DEBUG) and command errors via logging instead of a bare print - stream
    deaths were previously silent 3s-retry loops.
    - disconnect() now actually closes the gRPC channel.
    - _format_error recognizes ExperimentLockError in base64-encoded details.
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2026-07-06 feat(ph): generated protobuf stubs and a working I2C path; template teaches the stub pattern
    - Frontend pH connection uses compiled stubs (proto/ph_sensor_pb2.py) generated
    from the backend manifest; the temporary hand-rolled varint/LEN helpers are
    deleted from pH and from device_template, which now ships its own generated
    stubs (proto/my_device_pb2.py) so new devices copy the right pattern
    end-to-end. Verified against a live mock pH server.
    - Real-hardware I2C path fixed: server.py passed smbus2.SMBus directly to a
    driver expecting a raw write/read byte-stream interface (would have crashed
    with AttributeError on first use). New i2c_bus.SMBusI2C adapter bridges the
    two via i2c_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
    [server.py]
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2026-07-06 test+ci+docs: frontend test suite, CI workflow, architecture doc refresh
    - First frontend test suite (software/frontend/tests/, 15 tests, headless via
    make test): generator output structure + per-device golden checks (pytest
    twin of make check-connections), _format_error decoding, and
    server-labware->canvas spec conversion. pytest added as a dev dependency.
    - GitHub Actions CI (.github/workflows/ci.yml) runs both backend suites, the
    frontend suite, and both drift checks on push/PR - all previously
    manual-only make targets.
    - CURRENT_STATE.md refreshed: closed gaps removed (pH I2C, pH stubs, backend
    lock gating, mock I2C), new capabilities and stable decisions recorded
    (lock tok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
2026-07-08 positioning fixes, now able to home gantry relative to one corner (out of four), UI signal adjustments - Last homed now works, active toolhead now works, Last Calibrated now works - Skeleton code of 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
    [_cli.py, feature.py, interfaces.py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]
2026-07-09 add safe clearance-travel height in the gantry backend dervied from plate geometry
    [server.py]
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2026-07-15 new way to stabilize pH probe
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2026-07-23 new ph traces, fix read_stable, and change washing+sation config so it doesn't engage too deep
2026-08-04 Release v0.1.4: dosing pump device, gantry labware/rotation fixes, client logging resilience
    Adds the Atlas Scientific EZO-PMP dosing pump as a new device (backend, SiLA
    feature, client instrument, Qt widget), verified against real hardware
    (UART smoke test + a fixed serial-port concurrency race). Fixes the new
    24_well_15ml labware's off-center well grid and adds a rotated_270 orientation
    so its plates land correctly on the deck. Hardens RxnBenchClient.log() to skip
    an unwritable row instead of crashing the whole experiment run. See
    CHANGELOG.md [v0.1.4] for full details.
    [BOM.csv]
2026-08-05 Release v0.1.5: bundled example scripts/workspaces, log-overwrite fix, 24-well 5mL labware
    Packaging now stages Scripts/ and Workspaces/ folders next to the built exe
    (mirroring copy_device_plugins.py), with the Experiment Runner and workspace
    import dialogs defaulting to them. RxnBenchClient.set_log_output() no longer
    silently overwrites an existing results file. Adds 24_well_5ml labware and
    switches the 3_24-well_wWash workspace to it; washing_station depth/footprint
    adjusted. See CHANGELOG.md [v0.1.5] for full details.
2026-08-05 added documents and edits to readme
    [EZO-PMP.STEP]
2026-08-05 frontend: restructure all device plugins as installable entry-points packages
    Each device frontend (gantry, ph_sensor, camera, dosing_pump, device_template)
    moves from a flat devices/<name>/frontend/*.py tree (loaded by scanning
    devices/*/frontend/ and file-location importlib tricks) to a proper
    src/rxn_bench_<name>_frontend/ package with its own pyproject.toml declaring
    a "rxn_bench.devices" entry point, matching the src-layout convention backend
    device packages already use.
    Two coupling points existed identically across all five and are now fixed:
    - widget.py/__init__.py's `from ...discovery import DiscoveredServer`
    (relied on being loaded as rxn_bench_ui.devices.<name>) -> absolute
    `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
2026-08-05 backend: fix check-proto/gen-proto paths for the new frontend src-layout
    The backend's proto-drift check assumed the flat devices/<name>/frontend/proto/
    layout; it now points at devices/<name>/frontend/src/rxn_bench_<name>_frontend/proto/
    to match the entry-points restructure.
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2026-08-05 docs: record the device entry-points + submodule split
    Updates docs/ai/CURRENT_STATE.md's device-first layout, frontend layout,
    device plugin contract, and standalone executable packaging sections to
    match the new src/rxn_bench_<name>_frontend/ entry-points packages and the
    devices/*/{backend,frontend} submodule split; moves the now-resolved
    entry-points gap to Current Capabilities and adds a gap for pushing the
    10 split-out repos to GitHub and repointing .gitmodules; adds a Stable
    Design Decisions entry on keeping repo-topology and discovery-mechanism
    decisions orthogonal. CHANGELOG.md gets an Unreleased entry.
2026-08-05 devices: dissolve frontend/backend submodules before capability/driver restructure
    Temporary step: reverting to plain tracked directories so the capability
    vs. driver package split (backend files reorganized into two packages per
    device, hardware_models + toolhead configs relocated) can be done as normal
    file operations before re-splitting into the new devices/<name>/{capability,driver}
    submodule shape.
    [_cli.py]
2026-08-05 ph_sensor: split into capability + driver packages
    devices/ph_sensor/ now has two halves instead of one backend+frontend pair:
    - capability/{backend,frontend}: rxn_bench_ph (SiLA feature, PHSensorProtocol,
    mock, session logging) + rxn_bench_ph_sensor_frontend (widget/connection),
    hardware-agnostic - the "standardized, capability-based" layer.
    - driver/backend: rxn_bench_atlas_ezo_ph_driver, the concrete Atlas Scientific
    EZO-pH driver (I2C+UART transports, wire-protocol mocks), registered under
    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
    [pH Probe Lid.stl, pH Probe Mount.stl]
2026-08-06 camera: split into capability + driver packages
    Same shape as the ph_sensor split: capability/{backend,frontend} keeps
    rxn_bench_camera (CameraProtocol, feature, mock, image/session logging) +
    rxn_bench_camera_frontend; driver/backend adds rxn_bench_crowsnest_camera_driver
    (the Crowsnest HTTP client), registered under a new "rxn_bench.camera_drivers"
    entry-point group (crowsnest -> build_camera).
    Also fixes a real uv workspace limitation hit while doing this: declaring
    both capability and driver as `[tool.uv.workspace] members` with reciprocal
    `{workspace = true}` sources breaks package-metadata builds from a clean
    venv/lockfile (uv 0.11.21) - "not a workspace member" even though it is.
    Fix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
    [_cli.py, feature.py, interfaces.py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]
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2026-08-06 gantry: split into capability + driver packages; nest device_template
    Same shape as the other three devices: capability/{backend,frontend} keeps
    rxn_bench_gantry (MotionClientProtocol, controller, homing/toolhead/workspace
    managers, MockMoonrakerClient - a generic in-memory MotionClientProtocol
    simulator with no Moonraker wire-protocol emulation, so it stays capability-
    side unlike the pH/pump driver-level mocks) + rxn_bench_gantry_frontend.
    driver/backend adds rxn_bench_moonraker_driver (moonraker_client.py,
    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
    [Belt Clamp.stl, Mount Pin.stl, Mounting Plate.stl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]
2026-08-06 deploy: fix install/build scripts for the capability/driver path split
    install_service.sh: WORKING_DIR (the standalone-venv install target) now
    points at devices/<key>/capability/backend; a new DRIVER_DIR points at
    devices/<key>/driver/backend for the driver-setup hook (setup_drivers.sh -
    currently only pH sensor's, moved there since I2C setup is Atlas-specific).
    The editable install of the capability package already pulls its driver in
    transitively (a declared dependency), so no separate install step needed.
    install_offline.sh now runs aggregate_toolheads.py before install_service.sh,
    so gantry's bundled toolheads/ directory has the pH probe's config copied in
    before its venv is built from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
2026-08-06 devices: split each capability/driver package into its own git repo
    Same treatment as the earlier frontend/backend submodule split, applied to
    the new topology: devices/<name>/{capability,driver} (9 folders total - all
    4 real devices have both, device_template only has capability, no real
    driver to split out) are now git submodules pointing at standalone repos
    under ../rxn-bench-device-repos/ (local for now, pending GitHub hosting -
    same caveat as before). Pure git plumbing (git archive of tracked content
    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
    [Belt Clamp.stl, Mount Pin.stl, Mounting Plate.stl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]
2026-08-06 ci: run 'make install' (not bare uv sync) for the backend job
    CI's backend job called uv sync directly, skipping aggregate_toolheads.py -
    gantry's test_toolhead_manager.py tests were failing to find the pH probe's
    toolhead config once it moved out of gantry's own tree. make install already
    runs the aggregation step first; CI now uses it instead of duplicating.
    Also adds the .gitignore each of the 9 new capability/driver submodule repos
    was still missing (only the original 5 frontend/backend-era repos had one) -
    same __pycache__/.venv/build-cruft patterns as the rest.
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2026-08-06 docs: update all READMEs for the capability/driver split
    Every README that described the old devices/<name>/{backend,frontend} shape
    was stale after the capability/driver restructure - fixed throughout:
    - Top-level README.md and per-device READMEs (gantry/ph_sensor/camera/
    dosing_pump/device_template) now describe capability/ + driver/, with
    Supported-Devices.md linked as the registry.
    - Each capability package's README (backend/README.md) had its "swap the
    hardware" section rewritten from the old direct-injection pattern
    (`Feature(x=your_instance)` in server.py) to the real entry-points
    mechanism, and gained a pointer to its sibling driver package.
    - New devices/<name>/driver/REA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
2026-08-07 preparing to split repo into submodules
    [24-well_A1.csv, 24-well_A2.csv, 24-well_A3.csv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]
2026-08-07 dev snapshot: flatten device submodules into tree
    Temporary flattened snapshot for the dev branch: devices/*/{capability,driver}
    are committed as plain files here instead of git submodule links, since those
    9 packages don't have remotes yet. Includes the repo-wide cleanup pass
    (dead code, redundant comments, dash/arrow character sweep) applied across
    every device package. Local checkout keeps the real submodule structure;
    this only affects what's pushed to dev.
    [Belt Clamp.stl, Mount Pin.stl, Mounting Plate.stl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]
